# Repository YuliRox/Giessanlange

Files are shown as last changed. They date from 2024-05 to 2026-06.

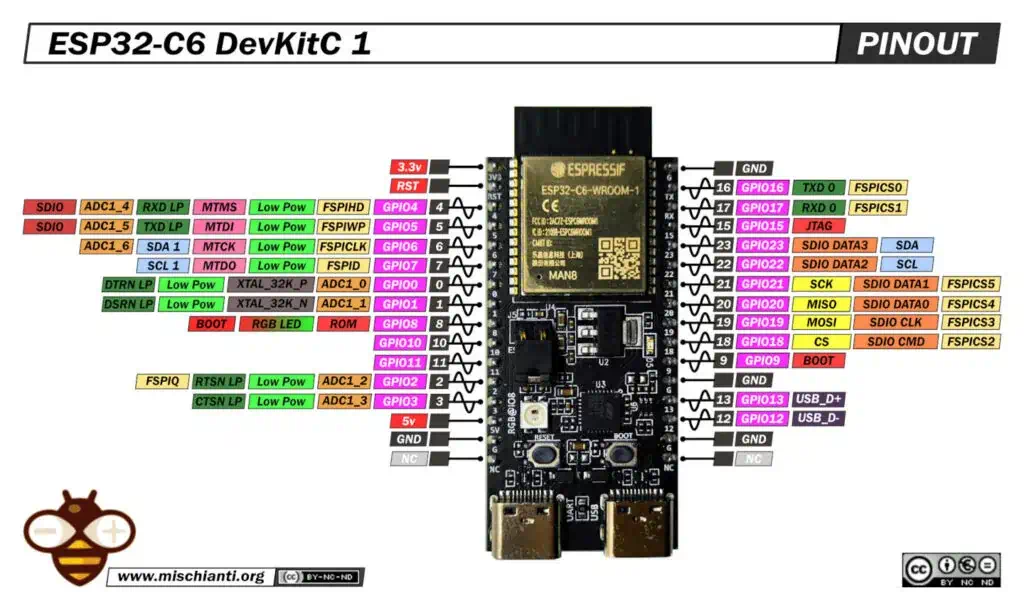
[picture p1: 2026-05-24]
docs/datasheets/Espressif-esp32-c6-devkitc-1-low-pinout.webp

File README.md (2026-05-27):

# Gießanlage

Solar-powered ESP32-C6 plant watering controller. Two channels, MOSFET pump driver, three buttons. Talks to a local MQTT broker for status / config (in progress).

## Hardware

- **Controller**: `ESP32-C6-DevKitC-1`
- **Pumps**: 2× DC pump, ~14 V / 24 W, switched low-side via `IRLZ34N` N-MOSFETs
- **Sensors**: Chirp soil moisture (I2C), VL53L0X TOF (I2C), A02YYUW ultrasonic (UART)
- **Display**: 2.9" tri-colour e-paper, SPI (Reichelt #253924)

For details:

- **Authoritative wiring** — `schematics/giessanlage/giessanlage.kicad_sch`
- **GPIO map** — `docs/GPIO_MAPPING.md`
- **Bill of materials** — `docs/HARDWARE_BOM.md`
- **Sensor wiring notes** — `docs/SENSOR_WIRING_NOTES.md`
- **MOSFET stage details** — `docs/ESP32_MOSFET_NEXT_STEPS.md`

The schematic is the source of truth. Docs follow it; firmware constants in `src/main.cpp` follow the docs.

## Project layout

```
src/main.cpp                 Arduino glue. The only file allowed to touch
                             Arduino headers, GPIO pin numbers, and millis().

lib/Giessanlage/             Pure state machine. Platform-independent.
                             Multi-channel, per-channel pumpTime, per-channel
                             API (Channel::One / Channel::Two).
lib/DebouncedButton/         Reusable button debouncer with std::function
                             PinReader injection. Native-testable.
lib/ChirpSensor/             I2C soil moisture wrapper.
lib/ToFSensor/               VL53L0X water-level wrapper.
lib/UltraschallSensor/       A02YYUW frame parser + UART glue.

test/test_logic/             Giessanlage state-machine tests (Unity).
test/test_button/            DebouncedButton tests.
test/test_chirp/             ChirpSensor tests.
test/test_ultraschall/       Ultrasonic frame parser tests.

docs/                        Hardware references (see list above) +
                             HAL_TESTABILITY.md (the pattern every lib/
                             component follows).

schematics/giessanlage/      KiCad project + schematic (authoritative).
```

The HAL pattern in `docs/HAL_TESTABILITY.md` is the project convention: classes that ultimately touch hardware take a `std::function` reader/writer at construction. `main.cpp` provides the real one (`digitalRead`/`digitalWrite` lambdas); tests provide a stub. This keeps every `lib/` component compilable and unit-testable in the `native` env.

## Build, flash, test

PlatformIO. Two environments in `platformio.ini`:

- `esp32-c6-devkitc-1` — real hardware target.
- `native` — host build for unit tests.

```bash
pio run                    # build for ESP32-C6 (default env)
pio run -t upload          # flash the device
pio device monitor         # serial monitor @ 115200 baud

pio test -e native                  # run all host unit tests
pio test -e native -f test_logic    # filter by suite directory name
```

WSL note: the `native` env needs `gcc`/`g++` on PATH. On Windows hosts, run the test commands from WSL Ubuntu (see `CLAUDE.local.md` if it exists locally for the exact venv invocation).

## Firmware API at a glance

`Giessanlage` is the state machine. Two channels, named `Channel::One` and `Channel::Two`. Per-channel `pumpTime`, shared `wateringInterval`. All time is injected via `tick(delta_ms)` — the class never calls `millis()`.

```cpp
using Channel = Giessanlage::Channel;

Giessanlage anlage(
    /*wateringTime=*/ Giessanlage::INTERVAL_24H,
    /*pumpTimeCh1=*/  Giessanlage::INTERVAL_30S,
    /*pumpTimeCh2=*/  Giessanlage::INTERVAL_30S);

// each tick of the main loop:
anlage.tick(elapsedMs);
digitalWrite(PUMP_1_GPIO, anlage.isPumping(Channel::One) ? HIGH : LOW);
digitalWrite(PUMP_2_GPIO, anlage.isPumping(Channel::Two) ? HIGH : LOW);

// user actions:
anlage.triggerPump(Channel::One);   // manual start
anlage.stopPump(Channel::One);      // manual stop
anlage.stopAllPumps();              // cancel button

// multi-channel aggregates:
anlage.isAnyPumping();              // any channel running?
anlage.triggerAllPumps();           // start every idle channel
```

Pump outputs are **active-high** N-MOSFET gate drive (`HIGH` = pump on). Buttons are `INPUT_PULLUP`, so closed = `LOW`.

## Status

## Development Container

A dev container (PlatformIO, Node, GitHub CLI, Claude Code, and a Mosquitto MQTT broker)
is provided for building, testing, and flashing. See `.devcontainer/README.md` for setup,
USB passthrough for the ESP32, and MQTT details.

## Related Notes
Working today: pump state machine, debounced buttons, MOSFET pump driver stage (schematic; firmware drives the gates correctly). All `native` test suites green.

In progress / planned: see the GitHub issue tracker. MVP milestone covers the baseplate assembly, WiFi + MQTT integration, on-device e-paper UI, and a few safety/diagnostics items.

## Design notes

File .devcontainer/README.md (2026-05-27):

# Dev Container

An Ubuntu-based dev container for building and testing the firmware, wired through
`docker-compose.yml`. It provides PlatformIO Core, Node.js, and the Claude Code CLI,
and runs as the non-root `vscode` user.

## What's inside

- **PlatformIO Core** (`pio`) installed into a venv on `PATH` — build with `pio run`,
  test with `pio test -e native`.
- **Node.js**, **GitHub CLI** (`gh`), and the **Claude Code** CLI, added via dev
  container features.
- An **Eclipse Mosquitto** MQTT broker (the `mqtt` service) for testing.
- VS Code extensions: PlatformIO IDE, C/C++, Python.

## Usage

Open the folder in VS Code and run **Dev Containers: Reopen in Container**, or use the
Dev Containers CLI. The PlatformIO download cache persists across rebuilds in the
`pio-cache` named volume.

## Persistence and credentials

- Claude Code config/state — settings, history, caches, **and credentials** — lives in
  the gitignored, repo-scoped folder `.devcontainer/.claude-home`, bind-mounted at
  `~/.claude`. It persists across rebuilds and does not bleed into other repositories.
- Authenticate **once inside the container** by running `claude` and following the
  prompt; the token is written into `.claude-home` (writable, so OAuth token refresh
  works) and survives rebuilds. The host's `~/.claude` is intentionally **not** mounted:
  a read-only credentials mount blocks token refresh and re-auth from persisting, and a
  read-write one would let the container modify host credentials. To avoid an interactive
  login you can instead set a long-lived `CLAUDE_CODE_OAUTH_TOKEN` (from
  `claude setup-token`) via `containerEnv` or a Codespaces secret.
- Claude Code telemetry, error reporting, and other non-essential traffic are disabled
  via `CLAUDE_CODE_DISABLE_NONESSENTIAL_TRAFFIC=1`.

## MQTT broker (testing)

An Eclipse Mosquitto broker runs as the `mqtt` service and starts alongside the dev
container (via `depends_on`).

- **From the dev container:** `mqtt://mqtt:1883` (Compose resolves the service name).
- **From the host:** `localhost:1883`, plus MQTT-over-WebSockets on `9001`.
- **Authentication is required** — anonymous access is disabled. Credentials come from
  `MQTT_USERNAME` / `MQTT_PASSWORD`, seeded into the broker's password file on each start.
  Defaults are `tester` / `testpass`; override them by copying `.env.example` to
  `.devcontainer/.env` (gitignored) and editing the values, then rebuilding.

Quick check from the host (or the container, using host `mqtt`):

```bash
mosquitto_sub -h localhost -p 1883 -u tester -P testpass -t 'test/#' &
mosquitto_pub -h localhost -p 1883 -u tester -P testpass -t 'test/hello' -m 'hi'
```

The config lives in `.devcontainer/mosquitto/mosquitto.conf`; broker data persists in the
`mqtt-data` volume. These settings are for local testing only — do not reuse them in
production.

## USB passthrough (flashing the ESP32)

Serial passthrough is **opt-in**: by default `devcontainer.json` lists only
`docker-compose.yml`, so the container builds without a board attached. To flash/monitor,
add `docker-compose.usb.yml` to the `dockerComposeFile` array in `devcontainer.json`
(keep this change local — don't commit it), then rebuild/reopen. That overlay maps
`/dev/ttyUSB0` (the CP210x UART bridge) into the container. If your C6 is wired through
its **native USB** port instead, it enumerates as `/dev/ttyACM0` — update the mapping in
`docker-compose.usb.yml`.

A `postStartCommand` in `devcontainer.json` `chgrp dialout` + `chmod g+rw` the device on
start (docker-desktop has no udev to do this), so the non-root `vscode` user can use it.

> **Important:** the device mapping is validated when the container is created, so the
> board must be reachable in the backend **before** you build/reopen the container.
> Prepare it first (see below), otherwise create fails with
> `error gathering device information ... no such file or directory`.

### Docker Desktop on Windows

Two host-side prerequisites must be satisfied before opening the container:

1. The board must be bound into WSL2 with
   [`usbipd-win`](https://github.com/dorssel/usbipd-win).
2. The `cp210x` driver must be loaded in the **docker-desktop** distro (the one the
   Docker daemon reads device paths from). It is **not auto-loaded**, and Docker Desktop
   does not persist the change, so it must be re-loaded after every Docker Desktop / WSL
   restart or replug.

The helper script does both. In an **administrator PowerShell on the host**:

```powershell
winget install usbipd    # once, if not already installed
powershell -ExecutionPolicy Bypass -File .devcontainer\usb-attach.ps1
```

Then build/reopen the dev container. The equivalent manual steps:

```powershell
usbipd list                            # find the BUSID of the CP2102N (10c4:ea60)
usbipd bind   --busid <BUSID>          # once per device (persists)
usbipd attach --wsl --busid <BUSID>    # attach into WSL2
wsl -d docker-desktop modprobe cp210x  # create /dev/ttyUSB0 in the docker daemon's distro
```

Verify inside the container:

```bash
ls -l /dev/ttyUSB0   # present and group-writable; vscode is in the dialout group
```

Building/testing without a board needs no action — the USB overlay is off by default.

### Linux host

`usbipd` and the `modprobe` step are not needed — the device is present directly once
the board is plugged in (typically with a working udev rule for the `dialout` group).
Adjust the mapping in `docker-compose.usb.yml` if the board enumerates under a different
path.

### Note on the upload port

`platformio.ini` sets `upload_port = COM7`, which is a Windows host port and does not
resolve inside the Linux container. To flash **from the container**, target
`/dev/ttyUSB0` (e.g. `pio run -t upload --upload-port /dev/ttyUSB0`) or remove the
`upload_port` line so PlatformIO auto-detects the single attached board on both host and
container.

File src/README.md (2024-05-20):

# Giessanlage Library

Manages the internal pump state. Handles pump timers and provides minimal configuration for timer duration.

```cpp

Giessanlage anlage;

// in update loop check to see if pump should be running
void loop() {
    // update internal state
    anlage.tick(time_since_last_update);

    bool isPumping = anlage.isPumping();
    if(isPumping) {
        // run electricity to pummp
    } else {
        // retrieve exposed state
        Giessanlage::State state = anlage.getState(); // should be State::Idle if not pumping
    }
}

// try to start a manual pumping process (unscheduled)
if(anlage.triggerPump()) {
    // check if pump should be running
    bool isPumping = anlage.isPumping(); //->true

    // remaining time to run the pump (ms)
    unsigned long remainingPumpTime = anlage.getRemainingPumpTime();
    // time until next scheduled pump interval starts (ms)
    unsigned long remainingWateringInterval = anlage.getRemainingWateringInterval();
}

if(anlage.stopPump()) {
    bool isPumping = anlage.isPumping(); //->false
}

```

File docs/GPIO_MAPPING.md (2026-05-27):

# GPIO Mapping

This document summarizes the current `ESP32-C6-DevKitC-1` GPIO usage for the rework.

Source of truth:

- `schematics/giessanlage/giessanlage.kicad_sch` — for everything actually wired today.
- This file — for additional locked-in allocations not yet on the schematic (e-paper display, battery ADC).

## Current Functional Mapping

Wired in the schematic today:

- `GPIO0`  -> `TOF XSHUT`
- `GPIO1`  -> cancel button, `INPUT_PULLUP`
- `GPIO6`  -> shared `I2C SDA` (Chirp + TOF)
- `GPIO7`  -> shared `I2C SCL` (Chirp + TOF)
- `GPIO10` -> pump 2 button, `INPUT_PULLUP`
- `GPIO11` -> pump 1 button, `INPUT_PULLUP`
- `GPIO16` -> ultrasonic sensor power enable, PMOS gate via 100R series
- `GPIO17` -> ultrasonic sensor UART receive
- `GPIO22` -> pump 2 MOSFET gate (`Q2`)
- `GPIO23` -> pump 1 MOSFET gate (`Q1`)

Wired in the schematic for the e-paper display (added 2026-05-25):

- `GPIO18` -> e-paper display `DIN` (`SPI MOSI`)
- `GPIO19` -> e-paper display `CLK` (`SPI SCK`)
- `GPIO20` -> e-paper display `CS`, active-low
- `GPIO21` -> e-paper display `RST`, active-low
- `GPIO3`  -> e-paper display `DC` (data/command select) — consumes `ADC1_CH3`
- `GPIO2`  -> e-paper display `BUSY`, input — consumes `ADC1_CH2`

Reserved for a future build (not yet wired):

- `GPIO4`  -> battery voltage divider, `ADC1_CH4` (see #35)

Reserved as spare ADC:

- `GPIO5`  -> last remaining ADC-capable pin, `ADC1_CH5`

## ADC Capability (ESP32-C6)

The ESP32-C6 has **only ADC1** (no ADC2) with 7 channels:

| Channel | GPIO | Status |
|---|---|---|
| ADC1_CH0 | GPIO0  | consumed (TOF XSHUT, digital) |
| ADC1_CH1 | GPIO1  | consumed (cancel button, digital) |
| ADC1_CH2 | GPIO2  | consumed (e-paper BUSY, digital) |
| ADC1_CH3 | GPIO3  | consumed (e-paper DC, digital) |
| ADC1_CH4 | GPIO4  | **battery voltage divider** |
| ADC1_CH5 | GPIO5  | spare |
| ADC1_CH6 | GPIO6  | consumed (I2C SDA) |

## Pins to Avoid

- `GPIO8`, `GPIO9` — boot-mode strapping pins. Wrong level at reset causes the chip to fail to boot. **Do not repurpose.**
- `GPIO12`, `GPIO13` — USB-Serial-JTAG (D-/D+). Repurposing breaks flashing and debugging over USB.
- `GPIO15` — strapping pin for ROM-message UART verbosity. Cosmetic only, but no reason to use.
- `GPIO14` — **does not exist on the DevKitC-1 headers.**

## Notes on Strapping Pins

The DevKitC-1 user guide labels `GPIO4`, `GPIO5`, `GPIO8`, `GPIO9`, `GPIO15` as strapping pins. The implications for *this* project:

- `GPIO4` / `GPIO5` — strap the JTAG source. Gated by the `JTAG_SEL_ENABLE` eFuse, which this project will never burn. The strap sample is read into a discard register at reset and has no functional effect. Pad-JTAG over GPIO4/5/6/7 is already permanently unavailable on this board because GPIO6/7 are used for I2C. **Safe to use as ADC.**
- `GPIO8` / `GPIO9` — chip boot mode. Hard requirement to leave unconnected (or pulled to the safe boot levels).
- `GPIO15` — ROM message verbosity at boot. Cosmetic.

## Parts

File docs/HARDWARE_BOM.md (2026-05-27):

# Hardware BOM

This document is the consolidated hardware bill of materials for the current rework of the watering device.

Current design assumptions:

- controller is `ESP32-C6-DevKitC-1`
- `2` DC pumps, each about `14V / 24W`
- one low-side `N-MOSFET` switch channel per pump
- pump channels are independently controllable
- `Chirp`, `VL53L0X`, and ultrasonic sensor are powered from `ESP32 3V3`
- gate pulldown resistors are `10k ohm`
- the KiCad schematic is the source of truth for concrete part/value choices

## Core Control Electronics

- `1x` `ESP32-C6-DevKitC-1`
- `1x` perfboard or stripboard
- `1x` header/socket set for the ESP32 board, if needed

## Pump Driver Stage

- `2x` `IRLZ34N`
- `2x` `1N4004`
- `2x` `100 ohm` gate resistor
- `2x` `10k ohm` gate pulldown resistor

## Sensor Power Switching

- `1x` `IRLML6402` for ultrasonic sensor high-side power switching
- `1x` `100 ohm` gate resistor
- `1x` `10k ohm` gate pull-up resistor to `3V3`

KiCad references:

- `Q1`, `Q2`: `IRLZ34N`
- `D1`, `D2`: `1N4004`
- `R1`, `R3`: `100 ohm`
- `R2`, `R4`: `10k ohm`
- `Q3`: `IRLML6402`
- `R7`: `100 ohm`
- `R8`: `10k ohm`

## Sensors

- `1x` ultrasonic sensor marked `A0221AM 38M1056` (https://www.dfrobot.com/product-1935.html)
- `1x` `TOF200C-VL53L0X`
- `1x` `Chirp` soil moisture sensor, version `2.7.5` (https://wemakethings.net/chirp/)

## Display

- `1x` `2.9"` e-paper display, black/white/red, Reichelt #253924 (https://www.reichelt.de/de/de/shop/produkt/entwicklerboards_-_display_epaper_2_9_schwarz_weiss_rot-253924)

Notes:

- e-paper, not OLED — pick because it is sunlight-readable and draws ~zero current between refreshes, both critical for a solar-powered outdoor device
- interface is `SPI`, not I2C — pin assignments TBD; will need SPI pins (`SCK`, `MOSI`) plus `CS`, `DC`, `RST`, and `BUSY` allocated on the ESP32-C6
- refresh is slow (seconds for a full update); the firmware status screen should redraw infrequently, not every loop tick

## I2C Support Parts

- `2x` `4.7k ohm` resistor for `SDA` and `SCL` pull-ups to `3V3`

KiCad references:

- `R5`, `R6`: `4.7k ohm`

## Connectors and Terminals

- `5x` 2-pin screw terminal blocks
- `1x` 3-pin screw terminal block, or equivalent power distribution terminal
- `1x` `GX16` 4-pin connector set for the ultrasonic sensor
- `2x` `GX16` 6-pin connector sets for `Chirp` and `TOF`

Typical use:

- pump 1 output
- pump 2 output
- power input
- spare distribution / convenience
- sensor or auxiliary breakout as needed

Sensor connector note:

- `GX16-4` is planned for the ultrasonic sensor
- `GX16-6` is planned for the `Chirp` and `TOF` sensors

## Existing System Parts Retained

These are part of the system but not newly introduced by the rework:

- `2x` lead-acid battery, `12V 7.2Ah`
- `1x` solar charge controller with USB-A power outputs
- `2x` DC pump, about `14V / 24W`
- `1x` runtime potentiometer, if retained
- `1x` `12h/24h` interval switch, if retained
- manual and cancel buttons, if retained

## Current Pin Plan

See `docs/GPIO_MAPPING.md` for the authoritative GPIO map. Summary:

- `GPIO0`  -> `TOF XSHUT`
- `GPIO1`  -> cancel button, `INPUT_PULLUP`
- `GPIO2`  -> e-paper `BUSY`
- `GPIO3`  -> e-paper `DC`
- `GPIO4`  -> reserved for battery voltage divider, `ADC1_CH4` (future)
- `GPIO6`  -> shared `I2C SDA`
- `GPIO7`  -> shared `I2C SCL`
- `GPIO10` -> pump 2 button, `INPUT_PULLUP`
- `GPIO11` -> pump 1 button, `INPUT_PULLUP`
- `GPIO16` -> ultrasonic sensor power enable, active-low PMOS gate
- `GPIO17` -> ultrasonic sensor UART receive
- `GPIO18` -> e-paper `DIN` (`SPI MOSI`)
- `GPIO19` -> e-paper `CLK` (`SPI SCK`)
- `GPIO20` -> e-paper `CS`
- `GPIO21` -> e-paper `RST`
- `GPIO22` -> pump 2 MOSFET gate (`Q2`)
- `GPIO23` -> pump 1 MOSFET gate (`Q1`)

## Notes

- The `VL53L0X` and `Chirp` share the same I2C bus
- `Chirp` default I2C address: `0x20`
- `VL53L0X` expected default I2C address: `0x29`
- The ultrasonic sensor is treated as a `3.3V` UART-output sensor
- The ultrasonic sensor `VCC` is switched by `Q3` rather than tied directly to `3V3`
- The `ESP32-C6-DevKitC-1` `3V3` rail should be able to power the three sensors together under normal conditions

## Related Documents

- `ESP32_MOSFET_NEXT_STEPS.md`
- `SENSOR_WIRING_NOTES.md`
- `GPIO_MAPPING.md`
- `README.md`

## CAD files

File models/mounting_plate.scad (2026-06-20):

// Mounting plate for PC 240011 G 5U enclosure (Unterteil)
// Screws onto all box bosses; carries Revolt NX-6815 controller + breadboard.
//
// ── All dimensions in mm. Edit parameters only — no numbers elsewhere. ───────

// ── Box reference (drawing 5U240011 G) ───────────────────────────────────────
box_outer_w         = 239;      // 240.3 nominal / 239 actual
box_outer_d         = 159;      // 160.3 nominal / 159 actual
box_inner_w         = 233;      // inner wall-to-wall, long axis  (234.3/233)
box_inner_d         = 153;      // inner wall-to-wall, short axis (154.3/153)
protrusion_span_h   = 216;      // clear span between corner protrusions, horizontal
protrusion_span_v   = 116.7;    // clear span between corner protrusions, vertical

// ── Corner protrusion cutouts (derived from drawing) ─────────────────────────
corner_cut_x    = (box_inner_w - protrusion_span_h) / 2;   // = 8.5 mm
corner_cut_y    = (box_inner_d - protrusion_span_v) / 2;   // = 18.15 mm
corner_margin   = 0.5;   // extra clearance added to each cutout side
corner_cut_r    = 6;     // inner fillet radius matching box R6
corner_chamfer  = 2.5;   // leg of the 45° chamfer at the outer step corners

// ── Plate geometry ────────────────────────────────────────────────────────────
plate_fit_margin = 1;    // total clearance so plate slides into box (split across both sides)
plate_w         = box_inner_w - plate_fit_margin;
plate_d         = box_inner_d - plate_fit_margin;
plate_t         = 3;
plate_corner_r  = 4;

// ── Mid-edge notches (top and bottom centre, lid-screw bumps) ─────────────────
mid_notch_depth = (box_inner_d - 136) / 2 + 1.5;   // = 16.5 mm + 1.5 clearance
mid_notch_width = 16;             // estimated — tune to match actual bump width
mid_notch_r     = 4;              // fillet radius on the notch corners

// ── Large bosses — all ø8.5 OD, ø4 inner, M4 clearance ──────────────────────
boss_clearance  = 4.5;

// Boss A — 4 outer-corner bosses
boss_a_h        = 201.4;   // C-C horizontal
boss_a_v        = 138;     // C-C vertical

// Boss B — 4 inner-corner bosses (at base of corner protrusions)
boss_b_h        = protrusion_span_h;   // = 216 mm C-C horizontal
boss_b_v        = 75;                  // C-C vertical

// Boss C — 2 centre wall bosses (one per side wall, at vertical centre Y = 0)
// Vertically aligned with Boss B (same X), centred between the two Boss B rows.
boss_c_x        = boss_b_h / 2;   // = 108 mm — same wall ridge as Boss B
boss_c_y        = 0;

// Small bosses flanking Boss C (ø3, no thread) and tiny centre bosses (ø2):
// these are solid support pegs — they bear the plate from below, no holes needed.

// ── Revolt NX-6815 controller — M4 clearance ─────────────────────────────────
ctrl_hole_dia   = 4.3;
ctrl_h_spacing  = 50;      // C-C horizontal (rotated 90°)
ctrl_v_spacing  = 126.5;   // C-C vertical   (rotated 90°)
ctrl_wall_gap   = 40;      // distance from left plate edge to nearest controller hole
ctrl_center_x   = -plate_w/2 + ctrl_wall_gap + ctrl_h_spacing/2;
ctrl_center_y   = 0;       // group centre offset from plate centre, Y

// ── Breadboard / ESP32 — M2.5 clearance ──────────────────────────────────────
// Breadboard oriented so long axis (155 mm) runs along plate_w.
bb_hole_dia     = 3.0;
bb_h_spacing    = 155;     // C-C along plate width  (long axis of breadboard)
bb_v_spacing    = 89;      // C-C along plate depth  (short axis)
bb_center_x     = 22;      // group centre offset from plate centre, X
bb_center_y     = 0;       // group centre offset from plate centre, Y

// ── Internal ──────────────────────────────────────────────────────────────────
eps = 0.5;
$fn = 64;

// ── Modules ───────────────────────────────────────────────────────────────────

// Solid rounded-rectangle plate, geometric centre at origin, Z = 0..plate_t
module rounded_plate() {
    translate([0, 0, plate_t / 2])
        minkowski() {
            cube([plate_w - 2*plate_corner_r,
                  plate_d - 2*plate_corner_r,
                  plate_t - eps], center = true);
            cylinder(r = plate_corner_r, h = eps);
        }
}

// 4 through-holes at (±h/2, ±v/2)
module hole_pattern(h, v, dia) {
    for (sx = [-1, 1]) for (sy = [-1, 1])
        translate([sx * h/2, sy * v/2, -eps])
            cylinder(d = dia, h = plate_t + 2*eps);
}

// Single through-hole at (x, y)
module single_hole(x, y, dia) {
    translate([x, y, -eps])
        cylinder(d = dia, h = plate_t + 2*eps);
}

// Rounded-rectangle cutout, w × d, with inner fillet radius r, centred at origin
module rounded_cutout(w, d, r) {
    translate([0, 0, -eps])
        linear_extrude(height = plate_t + 2*eps)
            offset(r = r)
                square([max(w - 2*r, eps), max(d - 2*r, eps)], center = true);
}

// ── Assembly ──────────────────────────────────────────────────────────────────
difference() {
    rounded_plate();

    // Boss A: 4 outer-corner bosses
    hole_pattern(boss_a_h, boss_a_v, boss_clearance);

    // Boss B: 4 inner-corner bosses (at protrusion base)
    hole_pattern(boss_b_h, boss_b_v, boss_clearance);

    // Boss C: 2 centre wall bosses
    single_hole(-boss_c_x, boss_c_y, boss_clearance);
    single_hole(+boss_c_x, boss_c_y, boss_clearance);

    // Revolt NX-6815 controller mounting holes
    translate([ctrl_center_x, ctrl_center_y, 0])
        hole_pattern(ctrl_h_spacing, ctrl_v_spacing, ctrl_hole_dia);

    // Breadboard mounting holes
    translate([bb_center_x, bb_center_y, 0])
        hole_pattern(bb_h_spacing, bb_v_spacing, bb_hole_dia);

    // Mid-edge notches: top and bottom centre lid-screw bumps
    // Centred on plate edge so outer half falls outside plate — only inner corners are rounded.
    for (sy = [-1, 1])
        translate([0, sy * plate_d/2, 0])
            rounded_cutout(mid_notch_width, 2*mid_notch_depth, mid_notch_r);

    // Corner protrusion cutouts — centred on plate corner so outer faces fall outside
    // the plate and get clipped; only the single inner corner gets the fillet.
    for (sx = [-1, 1]) for (sy = [-1, 1])
        translate([sx * plate_w/2, sy * plate_d/2, 0])
            rounded_cutout(2 * (corner_cut_x + corner_margin),
                           2 * (corner_cut_y + corner_margin),
                           corner_cut_r);

    // 45° chamfers at the 8 outer step corners: subtract a cube rotated 45° centred at each
    // junction. The parts of the cube outside the plate cut nothing; the overlapping quarter
    // removes the sharp corner. No winding issues.
    for (sx = [-1, 1]) for (sy = [-1, 1]) {
        // Junction: top/bottom plate edge meets cutout vertical wall
        translate([sx * (plate_w/2 - (corner_cut_x + corner_margin)),
                   sy * plate_d/2, plate_t/2])
            rotate([0, 0, 45])
            cube([corner_chamfer * sqrt(2), corner_chamfer * sqrt(2), plate_t + 2*eps],
                 center = true);
        // Junction: left/right plate edge meets cutout horizontal wall
        translate([sx * plate_w/2,
                   sy * (plate_d/2 - (corner_cut_y + corner_margin)), plate_t/2])
            rotate([0, 0, 45])
            cube([corner_chamfer * sqrt(2), corner_chamfer * sqrt(2), plate_t + 2*eps],
                 center = true);
    }
}

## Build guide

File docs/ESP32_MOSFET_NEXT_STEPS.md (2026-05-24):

# ESP32-C6 + MOSFET Pump Control: Next Steps

This document describes how to replace the Arduino Nano + relay setup with an `ESP32-C6-DevKitC-1` and two independent MOSFET pump channels.

Assumptions:

- `2` DC pumps
- each pump is rated `14 V / 24 W`
- both pumps may be switched independently in the future
- switching is done with `N-channel` logic-level MOSFETs
- low-side switching is acceptable
- the existing solar charge controller and lead-acid battery setup remain in place
- no fuse is included in this design

## 1. Parts

Per build:

- `1x` `ESP32-C6-DevKitC-1`
- `2x` `IRLZ34N`
- `2x` `1N4004`
- `2x` `100 ohm` gate resistor
- `2x` `10k ohm` gate pulldown resistor
- `2x` `4.7k ohm` I2C pull-up resistor
- `1x` `IRLML6402` for ultrasonic sensor high-side power switching
- `1x` `100 ohm` resistor for the ultrasonic PMOS gate
- `1x` `10k ohm` pull-up resistor from ultrasonic PMOS gate to `3V3`
- `1x` perfboard or stripboard
- `1x` header set for the ESP32, if the board is not already socketed
- `5x` 2-pin screw terminal blocks
- `1x` 3-pin screw terminal block, or equivalent power distribution terminal
- `1x` `GX16-4` connector set for the ultrasonic sensor
- `2x` `GX16-6` connector sets for `Chirp` and `TOF`

Schematic-selected parts:

- `Q1`, `Q2`: `IRLZ34N`
- `D1`, `D2`: `1N4004`
- `R1`, `R3`: `100 ohm`
- `R2`, `R4`: `10k ohm`
- `R5`, `R6`: `4.7k ohm`
- `Q3`: `IRLML6402`
- `R7`: `100 ohm`
- `R8`: `10k ohm`

## 2. Recommended ESP32 Pins

Use GPIOs that are easy to access and avoid the obvious footguns:

- `GPIO18` for `Pump 1`
- `GPIO19` for `Pump 2`
- `GPIO16` for ultrasonic sensor power enable, active-low
- `GPIO17` for ultrasonic sensor UART receive
- `GPIO20` for `TOF_XSHUT`
- `GPIO6` for shared `I2C SDA`
- `GPIO7` for shared `I2C SCL`
- `GPIO2` for the potentiometer input, if you later reconnect an analog pot

Reasons:

- `GPIO18` and `GPIO19` are exposed on the DevKitC-1 header
- they are not listed as strapping pins
- they are not the default `USB-JTAG` pins

Avoid for this purpose unless you have a good reason:

- `GPIO4`, `GPIO5`, `GPIO8`, `GPIO9`, `GPIO15`: strapping pins
- `GPIO12`, `GPIO13`: USB-JTAG pins

Sources:

- ESP32-C6-DevKitC-1 header block
- ESP32-C6 GPIO restrictions documentation

## 3. Electrical Topology

Use one MOSFET channel per pump.

High-level power path:

- battery / charge controller `+` goes to both pump positive terminals
- each pump negative terminal goes to its own MOSFET `drain`
- each MOSFET `source` goes to common `GND`
- ESP32 `GND` must connect to the same common `GND`

High-level control path:

- `GPIO18` drives MOSFET channel 1 gate
- `GPIO19` drives MOSFET channel 2 gate
- `GPIO16` controls the ultrasonic sensor high-side PMOS
- `GPIO20` controls `TOF_XSHUT`
- `GPIO6` and `GPIO7` provide the shared I2C bus for `Chirp` and `TOF`

## 4. Ultrasonic Sensor Power Switching

The ultrasonic sensor is not tied directly to `3V3` in the current design.
Its `VCC` is switched by a high-side `P-channel` MOSFET so the ESP32 can depower it between measurements.

Wiring:

- `IRLML6402 Source` -> `3V3`
- `IRLML6402 Drain` -> ultrasonic sensor `VCC`
- `IRLML6402 Gate` -> `GPIO16` through `100 ohm`
- `IRLML6402 Gate` -> `3V3` through `10k ohm`

Behavior:

- `GPIO16 = LOW` -> ultrasonic sensor powered
- `GPIO16 = HIGH` -> ultrasonic sensor off

## 5. Per-Channel Wiring

For each pump channel:

- ESP32 GPIO -> `100 ohm` resistor -> MOSFET `gate`
- MOSFET `gate` -> `10k ohm` resistor -> `GND`
- MOSFET `source` -> `GND`
- MOSFET `drain` -> pump negative terminal
- pump positive terminal -> battery / charge controller positive rail
- flyback diode across the pump terminals

Flyback diode orientation:

- diode `cathode` to pump `+`
- diode `anode` to pump `-`

That means the diode is reverse-biased during normal operation and only conducts when the pump is switched off and the motor kicks back.

## 6. Text Schematic

```text
Pump supply +  -------------------+--------------------> Pump 1 +
                                  |
                                  +--------------------> Pump 2 +

Pump 1 - -------------------------> MOSFET 1 Drain
MOSFET 1 Source ------------------> GND
ESP32 GPIO18 --[100R]-------------> MOSFET 1 Gate
                      |
                    [10k]
                      |
                     GND

Pump 2 - -------------------------> MOSFET 2 Drain
MOSFET 2 Source ------------------> GND
ESP32 GPIO19 --[100R]-------------> MOSFET 2 Gate
                      |
                    [10k]
                      |
                     GND

ESP32 GND ------------------------> same GND as pump supply

Flyback diode on Pump 1:
  cathode -> Pump 1 +
  anode   -> Pump 1 -

Flyback diode on Pump 2:
  cathode -> Pump 2 +
  anode   -> Pump 2 -
```

## 7. Assembly Order

1. Mount the screw terminals on the perfboard.
2. Mount the two MOSFETs with enough spacing to wire them cleanly.
3. Add the two `100 ohm` gate resistors near the MOSFET gates.
4. Add the two `10k ohm` pulldown resistors from each gate to ground.
5. Create a common ground rail on the board.
6. Create a pump positive distribution rail on the board.
7. Wire each MOSFET source to the ground rail.
8. Wire each MOSFET drain to its own pump output terminal.
9. Bring the shared pump positive rail to the pump output terminals.
10. Install each flyback diode across its pump terminal pair, with the stripe toward pump positive.
11. Add the ESP32 header or socket connection.
12. Wire ESP32 `GND` to the board ground rail.
13. Wire `GPIO18` to pump channel 1 gate resistor input.
14. Wire `GPIO19` to pump channel 2 gate resistor input.
15. Add the `IRLML6402` high-side switch for the ultrasonic sensor.
16. Wire `GPIO16` to the ultrasonic PMOS gate resistor input.
17. Wire `GPIO20` to the `TOF_XSHUT` pin.
18. Wire the charge-controller or battery positive to the board pump positive input terminal.
19. Wire the charge-controller or battery ground to the board ground input terminal.

## 8. First Power-Up Sequence

Do not connect the pumps immediately.

1. Assemble the board completely except for the pumps.
2. Check continuity manually:
   - no short between pump `+` and `GND`
   - no short between MOSFET `gate` and `drain`
   - ESP32 `GND` is common with power `GND`
3. Power the ESP32 separately over USB-C first.
4. Flash a minimal test program that drives `GPIO18` and `GPIO19`.
5. Confirm the GPIO outputs toggle as expected.
6. Disconnect USB power.
7. Connect the pump supply.
8. Power the ESP32 again.
9. Verify that both pumps stay off at boot.
10. Connect one pump and test one channel.
11. Connect the second pump and test the second channel.

## 9. Minimal Firmware Plan

Initial migration goal:

- replace `D4 relay on/off` with `GPIO18` and `GPIO19`
- switch both outputs together first
- keep the option to separate them later

Practical first firmware behavior:

- when watering should run:
  - set `GPIO18 = HIGH`
  - set `GPIO19 = HIGH`
- when watering should stop:
  - set `GPIO18 = LOW`
  - set `GPIO19 = LOW`

Later, if you want independent control:

- pump 1 can stay on its current watering schedule
- pump 2 can get its own schedule, manual override, or zone assignment
- the ultrasonic sensor can be powered only for short sampling windows
- the `TOF` sensor can be put into hardware standby through `XSHUT`

## 10. Potentiometer Migration

If you keep the runtime potentiometer:

- outer pin 1 -> `3V3`
- outer pin 2 -> `GND`
- wiper -> `GPIO2` as ADC input

Important:

- the ESP32 ADC is `3.3 V` based
- do not feed `5 V` into the ESP32 analog input

## 11. Notes for Layout

- keep pump current wiring physically separate from the ESP32 signal wiring
- keep the flyback diodes close to the pump terminals or pump output terminals
- keep the gate resistors close to the MOSFET gates
- keep the shared ground path low-resistance and direct
- keep the ultrasonic PMOS close to the ESP32/sensor power routing
- keep the sensor cable connectors mechanically supported at the enclosure
- do not run pump current through breadboard spring contacts for permanent use

## 12. Migration Summary

Old design:

- Arduino Nano
- one relay output
- both pumps effectively treated as one switched load

New design:

- ESP32-C6-DevKitC-1
- two MOSFET outputs
- one PMOS high-side switch for the ultrasonic sensor
- each pump has its own switching channel
- firmware can run the pumps together now and separately later
- `Chirp` and `TOF` share I2C
- the ultrasonic sensor is power-gated for lower standby consumption

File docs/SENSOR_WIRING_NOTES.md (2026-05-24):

# Sensor Wiring Notes

This document captures the current sensor wiring plan for the `ESP32-C6-DevKitC-1`.

## ESP32 Pin Map

- `GPIO6` -> shared `I2C SDA`
- `GPIO7` -> shared `I2C SCL`
- `GPIO16` -> ultrasonic sensor power enable, active-low
- `GPIO17` -> ultrasonic sensor UART receive
- `GPIO18` -> `Pump 1` MOSFET gate
- `GPIO19` -> `Pump 2` MOSFET gate
- `GPIO20` -> `TOF_XSHUT`
- `GPIO2` -> potentiometer ADC input, if kept

## Ultrasonic Sensor

Sensor marking: `A0221AM 38M1056`

This appears to be an `A02YYUW`-type waterproof ultrasonic sensor with UART output.

Wire it like this:

- `VCC` -> switched `3V3` through the ultrasonic PMOS high-side switch
- `GND` -> `ESP32 GND`
- `TX` -> `ESP32 GPIO17`
- `RX` -> `3V3` for filtered output, or leave floating

Notes:

- Do not connect the sensor `TX` directly to the ESP32 if the sensor is powered from `5V`
- Preferred setup is to power the sensor from `3V3`
- Default UART speed is `9600 baud`
- `GPIO16` controls the ultrasonic `VCC` switch:
- `LOW` -> sensor powered
- `HIGH` -> sensor off

## TOF200C-VL53L0X

This sensor is treated as an `I2C` distance sensor.

Wire it like this:

- `VCC` -> `ESP32 3V3`
- `GND` -> `ESP32 GND`
- `SDA` -> `ESP32 GPIO6`
- `SCL` -> `ESP32 GPIO7`
- `SHUT/XSHUT` -> `ESP32 GPIO20`

Expected default I2C address:

- `0x29`

## Chirp Soil Moisture Sensor

Sensor version:

- `2.7.5`

Observed pins:

- `MISO`
- `SCL`
- `RESET`
- `VCC`
- `SDA/MOSI`
- `GND`

This sensor uses `I2C`.

Wire it like this:

- `VCC` -> `ESP32 3V3`
- `GND` -> `ESP32 GND`
- `SCL` -> `ESP32 GPIO7`
- `SDA/MOSI` -> `ESP32 GPIO6`
- `RESET` -> leave unconnected for now
- `MISO` -> leave unconnected

Notes:

- The default I2C address is `0x20`
- `MISO` is not needed for normal I2C operation
- `RESET` is optional because the sensor can be reset over I2C

## Shared I2C Bus

The `VL53L0X` and `Chirp` share the same I2C bus:

- `GPIO6` -> `SDA`
- `GPIO7` -> `SCL`

Attached devices:

- `VL53L0X` at `0x29`
- `Chirp` at `0x20`

## Sensor Connectors

The current connector plan is:

- ultrasonic sensor -> `GX16-4`
- `TOF200C-VL53L0X` -> `GX16-6`
- `Chirp` -> `GX16-6`

## I2C Pull-Ups

- `4.7k` from `SDA` to `3V3`
- `4.7k` from `SCL` to `3V3`

## 3V3 Power Budget

Current estimates for the sensors:

- ultrasonic sensor (`A02YYUW`-type): about `8 mA` average
- `VL53L0X`: about `19 mA` average while ranging, with brief peaks up to about `40 mA`
- `Chirp`: about `2.8 mA` at `3.3V` when polled continuously

Estimated totals:

- typical combined load: about `30 mA`
- short peak combined load: about `50 to 55 mA`

Conclusion:

- the `ESP32-C6-DevKitC-1` `3V3` rail should be able to power these three sensors together
- this assumes the DevKit is powered normally from `5V`
- if instability appears, the more likely issue is supply noise or transient load, not steady-state sensor current

Watch for:

- ESP32 resets when Wi-Fi starts
- I2C devices occasionally disappearing
- noisy or unstable readings during pump switching

## KiCad Representation

Recommended schematic representation:

- ultrasonic sensor: custom 4-pin symbol or `Connector_Generic:Conn_01x04`
- `VL53L0X`: custom I2C sensor symbol or suitable breakout/module symbol
- `Chirp 2.7.5`: custom 6-pin symbol or `Connector_Generic:Conn_01x06`

For the `Chirp` symbol, label the pins:

- `MISO`
- `VCC`
- `SCL`
- `SDA/MOSI`
- `RESET`
- `GND`

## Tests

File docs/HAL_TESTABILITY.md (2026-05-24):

# Hardware Abstraction & Testability

## Guiding principle

The existing `Giessanlage` state machine is already platform-independent: it takes a `delta_ms` argument and never calls `millis()`. The same separation should apply to any new Arduino-facing code. Hardware-touching logic lives in thin wrapper classes; all testable logic is kept free of Arduino headers.

## The problem with direct Arduino calls

```cpp
// Not testable on the native env — digitalRead() is undefined there
bool pollPressed(int pin) {
    return digitalRead(pin) == LOW;
}
```

When `env:native` runs, there is no `digitalRead`. Any class that calls it directly cannot be compiled or tested on the host.

## Pattern: inject the pin reader

The lightest-weight fix is **dependency injection via `std::function`**. The class holds a callable instead of a pin number, and callers provide the real `digitalRead` on hardware or a lambda in tests.

```cpp
// DebouncedButton.h
#pragma once
#include <functional>

class DebouncedButton {
public:
    using PinReader = std::function<int()>;

    // debounceMs: how long the pin must be stable before the edge is reported
    DebouncedButton(PinReader reader, unsigned long debounceMs = 100);

    // Call every loop tick. Returns true exactly once per closing edge.
    bool poll(unsigned long nowMs);

    bool isPressed() const;

private:
    PinReader _reader;
    unsigned long _debounceMs;
    int _state;        // last confirmed stable state
    int _lastReading;  // raw reading from previous poll
    unsigned long _lastChangeMs;
};
```

**On hardware** (`main.cpp`):
```cpp
#include <Arduino.h>
#include "DebouncedButton.h"

DebouncedButton buttonPump1([] { return digitalRead(BUTTON_PUMP_1); });
DebouncedButton buttonCancel([] { return digitalRead(BUTTON_CANCEL); });
```

The lambda captures `digitalRead` at call time — no Arduino include needed inside `DebouncedButton.cpp`.

**In tests** (`test/test_main.cpp`):
```cpp
#include "DebouncedButton.h"
#include <unity.h>

void test_debounce_fires_once_after_stable_low() {
    int fakePin = HIGH;
    DebouncedButton btn([&] { return fakePin; }, /*debounceMs=*/50);

    // raw press — not yet stable
    fakePin = LOW;
    TEST_ASSERT_FALSE(btn.poll(0));   // t=0: change detected, timer starts
    TEST_ASSERT_FALSE(btn.poll(30));  // t=30: still within debounce window

    // stable for long enough
    TEST_ASSERT_TRUE(btn.poll(60));   // t=60: edge confirmed, fires once
    TEST_ASSERT_FALSE(btn.poll(70));  // t=70: does not fire again
}
```

No hardware required; the test runs in `env:native`.

## Debounce algorithm

This project uses the **timer-based approach** (Mellis / Lady Ada, 2006, Arduino official examples). On each call to `poll(nowMs)`:

1. Read the pin via the injected `PinReader`.
2. If the raw reading differs from the previous reading, record `lastChangeMs = nowMs`.
3. If the reading has been stable for longer than `debounceMs` **and** differs from the last confirmed state, update the confirmed state and return `true` if the new stable state is `LOW` (closed).

This is robust, easy to reason about, and maps naturally onto the existing `loop()`/`tick()` structure.

An alternative is the **shift-register approach** (Ganssle):

```cpp
state = (state << 1) | digitalRead(pin) | 0xfe00;
if (state == 0xff00) { /* stable LOW for 8 consecutive reads */ }
```

It needs no timestamp at all — just a consistent call rate — and is more compact. The downside is that the debounce window is implicitly set by `loop()` frequency rather than by an explicit millisecond threshold, which is harder to reason about and harder to test deterministically.

## Full HAL: virtual interfaces

For more complex hardware (I2C sensors, the ultrasonic enable line, the TOF sensor) a virtual interface is the stronger pattern:

```cpp
// IGpio.h  — pure interface, no Arduino dependency
struct IGpio {
    virtual int read(int pin) const = 0;
    virtual void write(int pin, int value) = 0;
    virtual void pinMode(int pin, int mode) = 0;
    virtual ~IGpio() = default;
};
```

Production code receives an `IGpio&`; tests inject a mock. This is the pattern used by [arduino_abstractions](https://github.com/mum4k/arduino_abstractions) (GoogleMock-based) and described in [Designing a HAL in C++](https://blog.mbedded.ninja/programming/languages/c-plus-plus/designing-a-hal-in-cpp/).

For simple GPIO like buttons and pump outputs, the `std::function` injection (above) is sufficient and avoids the boilerplate of a full virtual hierarchy.

## Layer summary

| Layer | File(s) | Arduino dependency | Testable on native |
|---|---|---|---|
| Core logic | `Giessanlage.h/.cpp` | None | Yes |
| Button debounce | `DebouncedButton.h/.cpp` | None (injected) | Yes |
| Hardware wiring | `main.cpp` | Yes (`Arduino.h`) | No |

## References

- David Mellis / Lady Ada — [Arduino debounce tutorial](https://docs.arduino.cc/built-in-examples/digital/Debounce/) (original timer-based approach)
- Jack Ganssle — [A Guide to Debouncing](http://www.ganssle.com/debouncing.htm) (shift-register approach)
- ElectronVector — [When you want to unit test... abstract the hardware](http://www.electronvector.com/blog/when-you-want-to-unit-test-abstract-the-hardware)
- mum4k — [arduino_abstractions](https://github.com/mum4k/arduino_abstractions) (virtual interface + GoogleMock pattern)
- mbedded.ninja — [Designing a HAL in C++](https://blog.mbedded.ninja/programming/languages/c-plus-plus/designing-a-hal-in-cpp/)
- e-tinkers — [The simplest button debounce solution](https://www.e-tinkers.com/2021/05/the-simplest-button-debounce-solution/)

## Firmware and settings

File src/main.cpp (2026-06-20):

#include <Arduino.h>
#include <Preferences.h>
#include <WiFi.h>
#include <map>
#include <string>

#include "Giessanlage.h"
#include "DebouncedButton.h"
#include "Secrets.h"
#include "WifiManager.h"

using Channel = Giessanlage::Channel;

Giessanlage anlage;
unsigned long startTime = 0UL;
unsigned long elapsedTime = 0UL;

namespace
{
constexpr int BUTTON_CLOSED = LOW;
constexpr int BUTTON_OPEN = HIGH;

// Pump outputs drive N-MOSFET gates in the current ESP32-C6 design.
constexpr int PUMP_ON = HIGH;
constexpr int PUMP_OFF = LOW;

// NVS namespace shared by Secrets and any future Preferences-backed config.
constexpr const char *PREFS_NAMESPACE = "giessanlage";
constexpr int BUTTON_PUMP_1 = 11;
constexpr int BUTTON_PUMP_2 = 10;
constexpr int BUTTON_CANCEL = 1;
constexpr int PUMP_1_GPIO = 23;
constexpr int PUMP_2_GPIO = 22;
} // namespace

DebouncedButton buttonPump1([] { return digitalRead(BUTTON_PUMP_1); });
DebouncedButton buttonPump2([] { return digitalRead(BUTTON_PUMP_2); });
DebouncedButton buttonCancel([] { return digitalRead(BUTTON_CANCEL); });

Preferences prefs;

// RAM-only fallback store used when NVS init fails. Lets the device run
// on build-time credentials even with a corrupted Preferences partition;
// see setup() for the fallback wiring and the rationale logged at boot.
static std::map<std::string, std::string> ramFallbackStore;

// Lazily initialised after Preferences.begin() succeeds (or its fallback
// kicks in).
Secrets *secrets = nullptr;
WifiManager *wifi = nullptr;

const unsigned long outputRemainingWaitInterval = 60UL * 1000UL;
unsigned long outputRemainingWait = 0;

static int channelLabel(Channel ch)
{
    return static_cast<int>(ch) + 1;
}

void togglePump(Channel channel)
{
    if (anlage.isPumping(channel))
    {
        anlage.stopPump(channel);
        Serial.print("Pump ");
        Serial.print(channelLabel(channel));
        Serial.println(": off");
    }
    else
    {
        anlage.triggerPump(channel);
        Serial.print("Pump ");
        Serial.print(channelLabel(channel));
        Serial.println(": on");
    }
}

static const char *wifiStateName(WifiManager::State s)
{
    switch (s)
    {
    case WifiManager::State::Disconnected: return "Disconnected";
    case WifiManager::State::Connecting:   return "Connecting";
    case WifiManager::State::Connected:    return "Connected";
    }
    return "?";
}

void setup()
{
    delay(200);

    pinMode(BUTTON_PUMP_1, INPUT_PULLUP);
    pinMode(BUTTON_PUMP_2, INPUT_PULLUP);
    pinMode(BUTTON_CANCEL, INPUT_PULLUP);
    pinMode(PUMP_1_GPIO, OUTPUT);
    pinMode(PUMP_2_GPIO, OUTPUT);
    digitalWrite(PUMP_1_GPIO, PUMP_OFF);
    digitalWrite(PUMP_2_GPIO, PUMP_OFF);

    delay(800);
    Serial.begin(115200);

    startTime = millis();
    elapsedTime = startTime;

    delay(1000);

    Serial.println("Hello World Giessanlange!");
    Serial.print("PumpTime Ch1: ");
    Serial.print(anlage.getPumpTime(Channel::One));
    Serial.println("ms");
    Serial.print("PumpTime Ch2: ");
    Serial.print(anlage.getPumpTime(Channel::Two));
    Serial.println("ms");
    Serial.print("WateringInterval: ");
    Serial.print(anlage.getWateringInterval());
    Serial.println("ms");

    // Preferences.begin() can fail when the NVS partition is corrupted,
    // the namespace is invalid, or flash is out of free entries. The
    // failure is silent at the Arduino-API level — every subsequent
    // get/put returns "" / false — which would make the device look
    // like it had no credentials at all even when secrets.ini was
    // populated. Surface the failure on serial AND fall back to a
    // RAM-only KvStore so build-time credentials still drive WiFi
    // association this boot. Persistence is lost across reboots, but
    // the device remains reachable for diagnosis instead of going
    // silently offline.
    const bool nvsOk = prefs.begin(PREFS_NAMESPACE, /*readOnly=*/false);
    if (!nvsOk)
    {
        Serial.println("ERROR: NVS init failed — using build-time "
                       "credentials without persistence. Runtime "
                       "credential updates will be lost on reboot.");
    }

    Secrets::KvStore store = nvsOk
        ? Secrets::KvStore{
              [](const std::string &key) {
                  return std::string(prefs.getString(key.c_str(), "").c_str());
              },
              [](const std::string &key, const std::string &value) {
                  prefs.putString(key.c_str(), value.c_str());
              },
          }
        : Secrets::KvStore{
              [](const std::string &key) {
                  auto it = ramFallbackStore.find(key);
                  return it == ramFallbackStore.end() ? std::string() : it->second;
              },
              [](const std::string &key, const std::string &value) {
                  ramFallbackStore[key] = value;
              },
          };

    Secrets::BuildTimeValues build{
        WIFI_SSID,
        WIFI_PASS,
        MQTT_USER,
        MQTT_PASS,
        MQTT_BROKER,
    };

    secrets = new Secrets(std::move(store), build);

    // Configure the radio once for home-network station use. Persistent
    // credential storage is disabled because Secrets / NVS owns that;
    // letting the WiFi class double-write its own copy on every begin()
    // would just burn flash. Auto-reconnect lets the framework re-
    // associate after a transient AP drop without us re-issuing begin();
    // the WifiManager's Connected->Disconnected transition then only
    // fires on prolonged outages.
    WiFi.persistent(false);
    WiFi.mode(WIFI_STA);
    WiFi.setHostname("giessanlage");
    WiFi.setAutoReconnect(true);

    wifi = new WifiManager(
        [](const std::string &ssid, const std::string &pass) {
            Serial.print("WiFi: connecting to '");
            Serial.print(ssid.c_str());
            Serial.println("'");
            WiFi.begin(ssid.c_str(), pass.c_str());
        },
        []() { return WiFi.status() == WL_CONNECTED; },
        secrets->wifiSsid(),
        secrets->wifiPass());

    if (!secrets->hasCredentials())
        Serial.println("WiFi: no credentials configured — staying offline");
}

void loop()
{
    unsigned long currentTime = millis();
    elapsedTime = currentTime - startTime;

    if (elapsedTime < 100)
    {
        delay(50);
        return;
    }

    startTime = currentTime;
    outputRemainingWait += elapsedTime;

    anlage.tick(elapsedTime);

    if (wifi != nullptr && wifi->tick(elapsedTime))
    {
        const auto s = wifi->state();
        Serial.print("WiFi: ");
        Serial.print(wifiStateName(s));
        if (s == WifiManager::State::Connected)
        {
            Serial.print(" (");
            Serial.print(WiFi.localIP());
            Serial.print(")");
        }
        Serial.println();
    }

    digitalWrite(PUMP_1_GPIO, anlage.isPumping(Channel::One) ? PUMP_ON : PUMP_OFF);
    digitalWrite(PUMP_2_GPIO, anlage.isPumping(Channel::Two) ? PUMP_ON : PUMP_OFF);

    if (buttonPump1.poll(currentTime))
        togglePump(Channel::One);
    if (buttonPump2.poll(currentTime))
        togglePump(Channel::Two);
    if (buttonCancel.poll(currentTime))
    {
        if (anlage.stopAllPumps())
            Serial.println("Cancel: all pumps off");
    }

    if (outputRemainingWait >= outputRemainingWaitInterval)
    {
        if (!anlage.isAnyPumping())
        {
            unsigned long remainTime = anlage.getRemainingWateringInterval();
            Serial.print("Remaining until next watering: ");
            Serial.print(remainTime / 1000UL / 60UL);
            Serial.println("min");
        }
        outputRemainingWait = 0;
    }
}

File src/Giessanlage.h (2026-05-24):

#ifndef Giessanlage_h
#define Giessanlage_h

class Giessanlage
{
public:
    static const int CHANNEL_COUNT = 2;

    static const unsigned long INTERVAL_30S = 30UL * 1000UL;
    static const unsigned long INTERVAL_12H = 12UL * 60UL * 60UL * 1000UL;
    static const unsigned long INTERVAL_24H = 2UL * INTERVAL_12H;

    Giessanlage(
        const unsigned long wateringTime = INTERVAL_24H,
        const unsigned long pumpTime = INTERVAL_30S);

    enum State : int
    {
        Undefined = 0,

        Idle,
        PumpingManual,
        PumpingAuto,
    };

    State getState(const int channel) const;

    /// @brief true if any channel is currently pumping
    bool isPumping() const;
    bool isPumping(const int channel) const;

    bool allowStateChange(const int channel, const State newState) const;

    /// @brief central logic update loop
    /// @param delta time in ms since last update
    /// @return true if any channel changed state
    bool tick(const unsigned long delta);

    /// @brief start a manual pump cycle on all idle channels
    /// @return true if at least one channel transitioned
    bool triggerPump();
    /// @brief start a manual pump cycle on the given channel
    bool triggerPump(const int channel);

    /// @brief stop pumping on all channels currently pumping
    /// @return true if at least one channel transitioned
    bool stopPump();
    /// @brief stop pumping on the given channel
    bool stopPump(const int channel);

    bool setPumpTime(const unsigned long time);
    unsigned long getPumpTime() const;

    bool setWateringInterval(const unsigned long time);
    unsigned long getWateringInterval() const;
    bool resetWateringTimer();

    unsigned long getRemainingPumpTime(const int channel) const;
    unsigned long getRemainingWateringInterval() const;

private:
    struct Channel
    {
        State state = State::Undefined;
        unsigned long pumpTimer = 0;
    };

    Channel channels[CHANNEL_COUNT];

    unsigned long wateringTime = 0;
    unsigned long pumpTime = 0;
    unsigned long wateringTimer = 0;

    bool setState(const int channel, const State newState);
    bool isValidChannel(const int channel) const;
    bool allChannelsIdle() const;

    void resetWateringTimerInternal();
    void resetPumpTimerInternal(const int channel);
};

#endif

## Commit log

2024-05-20 fix: const overflow and initialization order for giessanlage
    [Giessanlage.h]
2024-05-20 feat: trigger automatic pumping and provide status changed information
2024-05-20 feat: reset watering timer on switch to State::Idle
2024-05-20 feat: explicit timer reset function and feedback on set operations
    [Giessanlage.h]
2024-05-20 feat: Include buttons, use giesanlage lib
2024-05-20 added pin mappings for nano digital pins
2024-05-20 feat: explicit timer reset via functions and sensible default timer values in case of invalid constructor
    [Giessanlage.h]
2024-05-20 Correct Pins and debouncing pattern
    [main.cpp]
2024-05-20 fix: use setState initialization logic and const signatures
    [Giessanlage.h]
2026-05-15 kicad added
    [giessanlage.kicad_pcb, giessanlage.kicad_sch]
2026-05-15 kicad hinzugefügt
    [giessanlage.kicad_sch]
2026-05-24 feat: schematics and doc update
    [giessanlage.kicad_sch]
2026-05-24 feat: managed ultrasonic sensor lib
2026-05-24 feat: managed ToF Sensor
2026-05-24 feat: Add wrapper for chirp sensor
2026-05-24 Multi-channel Giessanlage + HAL testability guide (#4)
    * docs: add CLAUDE.md
    * refactor: extend Giessanlage to multi-channel state machine
    Per-channel state and pump timer; shared watering timer only resets when all channels are idle. main.cpp updated for the new API.
    * docs: add HAL testability guide and devkit pinout image
    Document the dependency-injection pattern for keeping Arduino-facing code testable on env:native, using a DebouncedButton sketch as the worked example. References Mellis/Ganssle debounce algorithms and established HAL patterns.
    * fix: reset watering timer on every per-channel Idle transition
    Previously the multi-channel refactor guarded the watering-timer reset
    wit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
    [Giessanlage.h, main.cpp]
2026-05-25 HAL: move Giessanlage to lib, extract DebouncedButton (#10)
    * refactor: move Giessanlage into lib/ component
    Aligns the platform-independent state machine with the existing lib/
    layout (ChirpSensor, ToFSensor, UltraschallSensor) and removes the
    build_src_filter / test_build_src workaround in the native env — PIO's
    LDF picks the library up automatically for both targets.
    Refs #5
    * refactor: extract DebouncedButton as injected-reader HAL component
    Replaces the inline struct + pollPressed() in main.cpp with a reusable
    library that takes a std::function<int()> PinReader, matching the
    pattern described in docs/HAL_TESTABILITY.md. main.cpp now only touches
    Arduino APIs (digitalRead inside th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
    [main.cpp]
2026-05-25 feat: add baseplate for box
    [mounting_plate.scad]
2026-05-25 schematic: add e-paper, move pumps to GPIO22/23, buttons to GPIO10/11/1, TOF to GPIO0
    Reflects in-place schematic edits making KiCad the authoritative source
    of truth. Pumps and buttons swap from the old Nano-era layout, TOF
    XSHUT relocates from GPIO20 to GPIO0 to free GPIO20 for the e-paper
    CS line, and the 2.9" tri-colour e-paper (Reichelt #253924) lands on
    GPIO18/19/20/21/3/2.
    [giessanlage.kicad_sch]
2026-05-25 docs+main: align GPIO map and firmware constants with current schematic
    Schematic is now authoritative (commit 06e09e8). Update the docs and
    src/main.cpp pin constants to follow.
    docs/GPIO_MAPPING.md and docs/HARDWARE_BOM.md:
    - pumps: GPIO22 (pump 2 / Q2), GPIO23 (pump 1 / Q1)
    - buttons: GPIO11 (pump 1 / SW1), GPIO10 (pump 2 / SW2), GPIO1 (cancel)
    - TOF XSHUT: GPIO0
    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
2026-05-25 docs: refresh README for ESP32-C6 architecture and lib/ layout
    Replaces the Nano-era reconstructed pin map with a structured overview:
    hardware references point to the schematic + GPIO_MAPPING.md /
    HARDWARE_BOM.md as sources of truth instead of restating pins (which
    drifted before). Documents the lib/ layout, the HAL pattern, the
    Channel-enum API, and build/flash/test commands.
    Refs #32
2026-05-25 feat: WiFi connectivity with gitignored secrets flow
    Build-time creds via PlatformIO extra_configs (secrets.ini, gitignored)
    seed an NVS-backed Secrets store on first boot. WifiManager is a
    non-blocking reconnect state machine (Disconnected/Connecting/Connected)
    with exponential backoff, driven by injected begin/probe callables so
    the logic is platform-independent and host-testable. main.cpp owns the
    Arduino side: Preferences + WiFi.begin/status lambdas, periodic tick
    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
2026-05-25 feat(wifi): configure radio for home-network station mode in setup
    Pull the one-shot WiFi class setup out of the per-attempt beginConnect
    lambda and into setup(). Configuration:
    - WiFi.persistent(false) — Secrets / NVS owns credential storage;
    the WiFi class doesn't need to duplicate it.
    - WiFi.mode(WIFI_STA) — station mode only, no AP.
    - WiFi.setHostname("giessanlage") — appears under that name in the
    router DHCP table / mDNS.
    - WiFi.setAutoReconnect(true) — framework re-associates after a
    transient AP drop without us re-issuing begin(); the manager's
    Connected->Disconnected transition only fires on prolonged outages.
    Refs #23
    [main.cpp]
2026-05-25 docs: add README for Secrets and WifiManager components
    Both readmes explain why the component exists (the option-value
    argument from the PR review), the API surface, the Arduino-side wiring
    in main.cpp, and the testing pattern. Cross-references the relevant
    GitHub issues.
    Refs #23, #29
2026-05-25 sec: lock down secrets.ini access at three layers
    1. CLAUDE.md MUST-rule at the top of the file: never read/edit/display
    the protected file; point users at the .example template instead.
    2. .claude/settings.json gets shared (committed) deny rules covering
    Read/Edit/Write/NotebookEdit/Grep/Glob on the path, plus the common
    Bash file-reading commands (cat/head/tail/grep/rg/sed/awk/less/more
    /xxd/tee).
    3. .claude/hooks/block-secrets.sh + the PreToolUse hook in
    .claude/settings.json: intercepts Read/Edit/Write/NotebookEdit/Bash/
    PowerShell/Grep/Glob; emits a deny decision with reason if the tool
    input names the protected file. Word-boundary regex on the path
    avoids fals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
2026-05-25 fix(main): NVS-init failure + WifiManager tick() return value
    Two PR #47 review fixes in one commit since both touch src/main.cpp
    in adjacent regions.
    NVS init failure (Preferences.begin):
    The return value was previously ignored. On failure (corrupted NVS
    partition, namespace exhaustion, etc.) every subsequent prefs.getString
    / putString silently returned "" / false, so Secrets saw empty values,
    seeding never persisted, and hasCredentials() returned false. The
    device would log "no credentials configured — staying offline" even
    when secrets.ini WAS populated — a contradictory message and a
    needle-in-a-haystack failure mode in the field. Now:
    - Check the return value, log an ERROR line o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
    [main.cpp]
2026-05-26 feat: add Ubuntu devcontainer with PlatformIO, MQTT, and tooling
    Docker-compose-based dev container running as non-root vscode:
    - PlatformIO Core, Node, GitHub CLI, and Claude Code CLI
    - Eclipse Mosquitto broker (auth required, .env-configurable) for testing
    - Opt-in ESP32 USB passthrough with a usbipd/cp210x host helper for
    Docker Desktop on Windows
    - Repo-scoped, gitignored persistence for Claude Code state
    Also drops the hardcoded upload_port so PlatformIO auto-detects the board.
2026-05-26 fix(devcontainer): make USB passthrough opt-in and cover ttyACM0
    Drop docker-compose.usb.yml from the default dockerComposeFile so the
    container builds without a board attached (the device mapping is validated
    at create time and otherwise hard-fails). Extend postStartCommand to fix
    permissions on both /dev/ttyUSB0 (CP210x) and /dev/ttyACM0 (native USB-CDC).
    Update the dev container README to document USB as opt-in.
2026-06-17 fix(plate): widen mid-edge notches by 4 mm and deepen by 1 mm
    mid_notch_width: 12 → 16 (2 mm per side)
    mid_notch_depth clearance: +0.5 → +1.5 (+1 mm extra height)
    [mounting_plate.scad]
2026-06-17 fix(plate): add fillets at the 8 outer step corners of protrusion cutouts
    Box inner walls are rounded; the sharp 90° junctions where the straight
    plate edge meets the protrusion step cut walls collided with them.
    Adds corner_notch_r = 4 mm concave fillets at all 8 junction points.
    [mounting_plate.scad]
2026-06-17 Revert "fix(plate): add fillets at the 8 outer step corners of protrusion cutouts"
    This reverts commit 290f44c13faa318475997fa524d5d6ba236eb544.
    [mounting_plate.scad]
2026-06-17 fix(plate): chamfer the 8 outer step corners to clear the box inner wall
    Subtracts a 45° rotated cube (2.5 mm leg) at each junction where the
    straight plate edge meets the corner protrusion cutout wall.
    [mounting_plate.scad]
2026-06-17 chore: add .gitattributes to normalise line endings to LF
    Fixes WSL git showing files as modified after Windows git commits them
    with CRLF line endings.
    [giessanlage.kicad_sch]
2026-06-20 refactor(secrets): rename seed -> syncFromBuildTime
    "Seeding" implied one-time default insertion, but the code treats
    build-time macros as authoritative on every boot — a non-empty macro
    that differs from the stored value overwrites it. Rename the private
    method, doc comments, README, and test names to "sync" to reflect the
    actual boot-time reconciliation behavior.
